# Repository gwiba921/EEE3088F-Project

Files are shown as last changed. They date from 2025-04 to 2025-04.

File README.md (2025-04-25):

# EEE3088F-Project
# EEE3088F Project: Power Subsystem for Micro Mouse Robot

## 📌 Introduction

This project forms part of the EEE3088F course, focusing on the design and development of the **power subsystem** for a maze-solving robot known as a **micro mouse**. The micro mouse achieves autonomous navigation through a system modularized into:

- Processor
- Motherboard
- Sensing
- Power

Our responsibility lies in the **Power Module**, which ensures reliable power delivery to all electronic components of the micro mouse.

---

## ⚙️ 1. Problem Description

The micro mouse requires a stable and efficient power supply to drive its operations, which include movement, sensing, and computation. This project involves designing a power module capable of:

- Powering **four DC motors**
- Integrating **USB-C** for **9V output**
- Regulating **3.3V and 5V power rails**
- Enabling **dual battery charging modes**

All of this must be done while maintaining modular compatibility with the rest of the micro mouse system.

---

## 📐 2. Scope and Limitations

- **Scope**:  
  This project is limited to the **power subsystem only**. However, the design must remain compatible with the processor, motherboard, and sensing modules.

- **Constraints**:
  - Strict budget limit of **$70**
  - **No use of breadboard-based components**
  - Must meet **PCB dimension limits**: `82mm x 60mm`
  - Requires **individual reports** despite collaborative PCB design
  - PCB must be designed from scratch using **permitted components only**

---

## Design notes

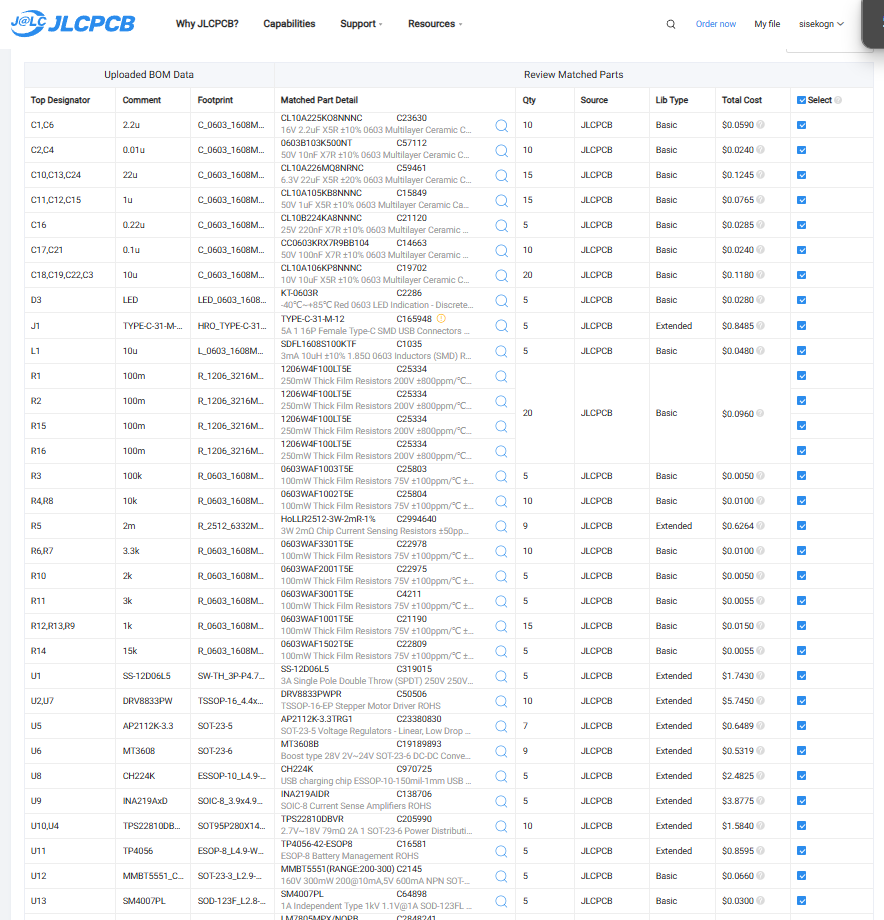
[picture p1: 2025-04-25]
ProLib_pcs_2025-03-23-2025-03-28_040031/jlcpcb/production_files/EEE3088F_Project_JLCPCBBOM_NNKGWI001_PLLCAM006.png

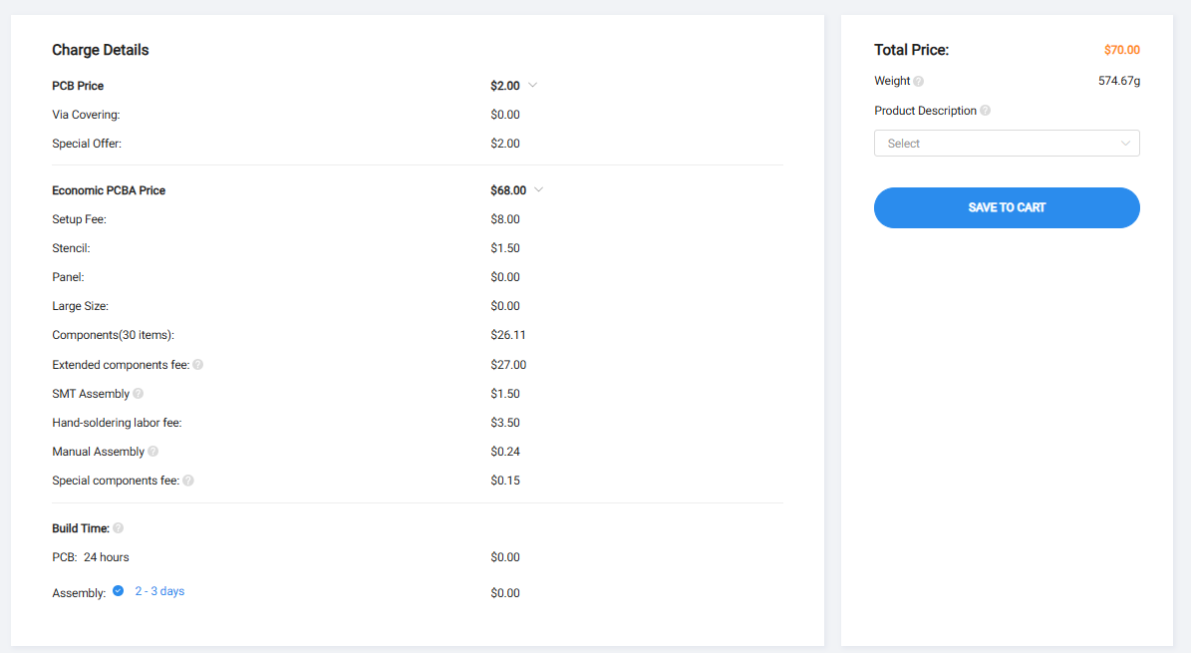
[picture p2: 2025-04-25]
ProLib_pcs_2025-03-23-2025-03-28_040031/jlcpcb/production_files/EEE3088F_Project_JLCPCBacceptance_NNKGWI001_PLLCAM006.png

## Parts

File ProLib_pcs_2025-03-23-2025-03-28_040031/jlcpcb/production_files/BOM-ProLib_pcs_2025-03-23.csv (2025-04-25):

Comment | Designator | Footprint | LCSC | Quantity
10u | L1 | L_0603_1608Metric_Pad1.05x0.95mm_HandSolder | C1035 | 1
INA219AxD | U9 | SOIC-8_3.9x4.9mm_P1.27mm | C138706 | 1
0.1u | C17,C21 | C_0603_1608Metric_Pad1.08x0.95mm_HandSolder | C14663 | 2
1u | C11,C12,C15 | C_0603_1608Metric_Pad1.08x0.95mm_HandSolder | C15849 | 3
TP4056 | U11 | ESOP-8_L4.9-W3.9-P1.27-LS6.0-BL-EP | C16581 | 1
TYPE-C-31-M-12 | J1 | HRO_TYPE-C-31-M-12 | C165948 | 1
MT3608 | U6 | SOT-23-6 | C19189893 | 1
10u | C18,C19,C22,C3 | C_0603_1608Metric_Pad1.08x0.95mm_HandSolder | C19702 | 4
TPS22810DBVR | U10,U4 | SOT95P280X145-6N | C205990 | 2
0.22u | C16 | C_0603_1608Metric_Pad1.08x0.95mm_HandSolder | C21120 | 1
1k | R12,R13,R9 | R_0603_1608Metric_Pad0.98x0.95mm_HandSolder | C21190 | 3
MMBT5551_C2145 | U12 | SOT-23-3_L2.9-W1.3-P1.90-LS2.4-BR | C2145 | 1
15k | R14 | R_0603_1608Metric_Pad0.98x0.95mm_HandSolder | C22809 | 1
LED | D3 | LED_0603_1608Metric_Pad1.05x0.95mm_HandSolder | C2286 | 1
2k | R10 | R_0603_1608Metric_Pad0.98x0.95mm_HandSolder | C22975 | 1
3.3k | R6,R7 | R_0603_1608Metric_Pad0.98x0.95mm_HandSolder | C22978 | 2
AP2112K-3.3 | U5 | SOT-23-5 | C23380830 | 1
2.2u | C1,C6 | C_0603_1608Metric_Pad1.08x0.95mm_HandSolder | C23630 | 2
100k | R3 | R_0603_1608Metric_Pad0.98x0.95mm_HandSolder | C25803 | 1
10k | R4,R8 | R_0603_1608Metric_Pad0.98x0.95mm_HandSolder | C25804 | 2
LM7805MPX_NOPB | VR1 | VREG_LM7805MPX_NOPB | C2848241 | 1
2m | R5 | R_2512_6332Metric_Pad1.40x3.35mm_HandSolder | C2994640 | 1
SS-12D06L5 | U1 | SW-TH_3P-P4.70_L11.1-W12.7 | C319015 | 1
3k | R11 | R_0603_1608Metric_Pad0.98x0.95mm_HandSolder | C4211 | 1
DRV8833PW | U2,U7 | TSSOP-16_4.4x5mm_P0.65mm | C50506 | 2
0.01u | C2,C4 | C_0603_1608Metric_Pad1.08x0.95mm_HandSolder | C57112 | 2
22u | C10,C13,C24 | C_0603_1608Metric_Pad1.08x0.95mm_HandSolder | C59461 | 3
SM4007PL | U13 | SOD-123F_L2.8-W1.8-LS3.7-RD | C64898 | 1
CH224K | U8 | ESSOP-10_L4.9-W3.9-P1.0-LS6.0-TL-EP | C970725 | 1
100m | R2 | R_1206_3216Metric_Pad1.30x1.75mm_HandSolder | C25334 | 1
100m | R1 | R_1206_3216Metric_Pad1.30x1.75mm_HandSolder | C25334 | 1
100m | R15 | R_1206_3216Metric_Pad1.30x1.75mm_HandSolder | C25334 | 1
100m | R16 | R_1206_3216Metric_Pad1.30x1.75mm_HandSolder | C25334 | 1

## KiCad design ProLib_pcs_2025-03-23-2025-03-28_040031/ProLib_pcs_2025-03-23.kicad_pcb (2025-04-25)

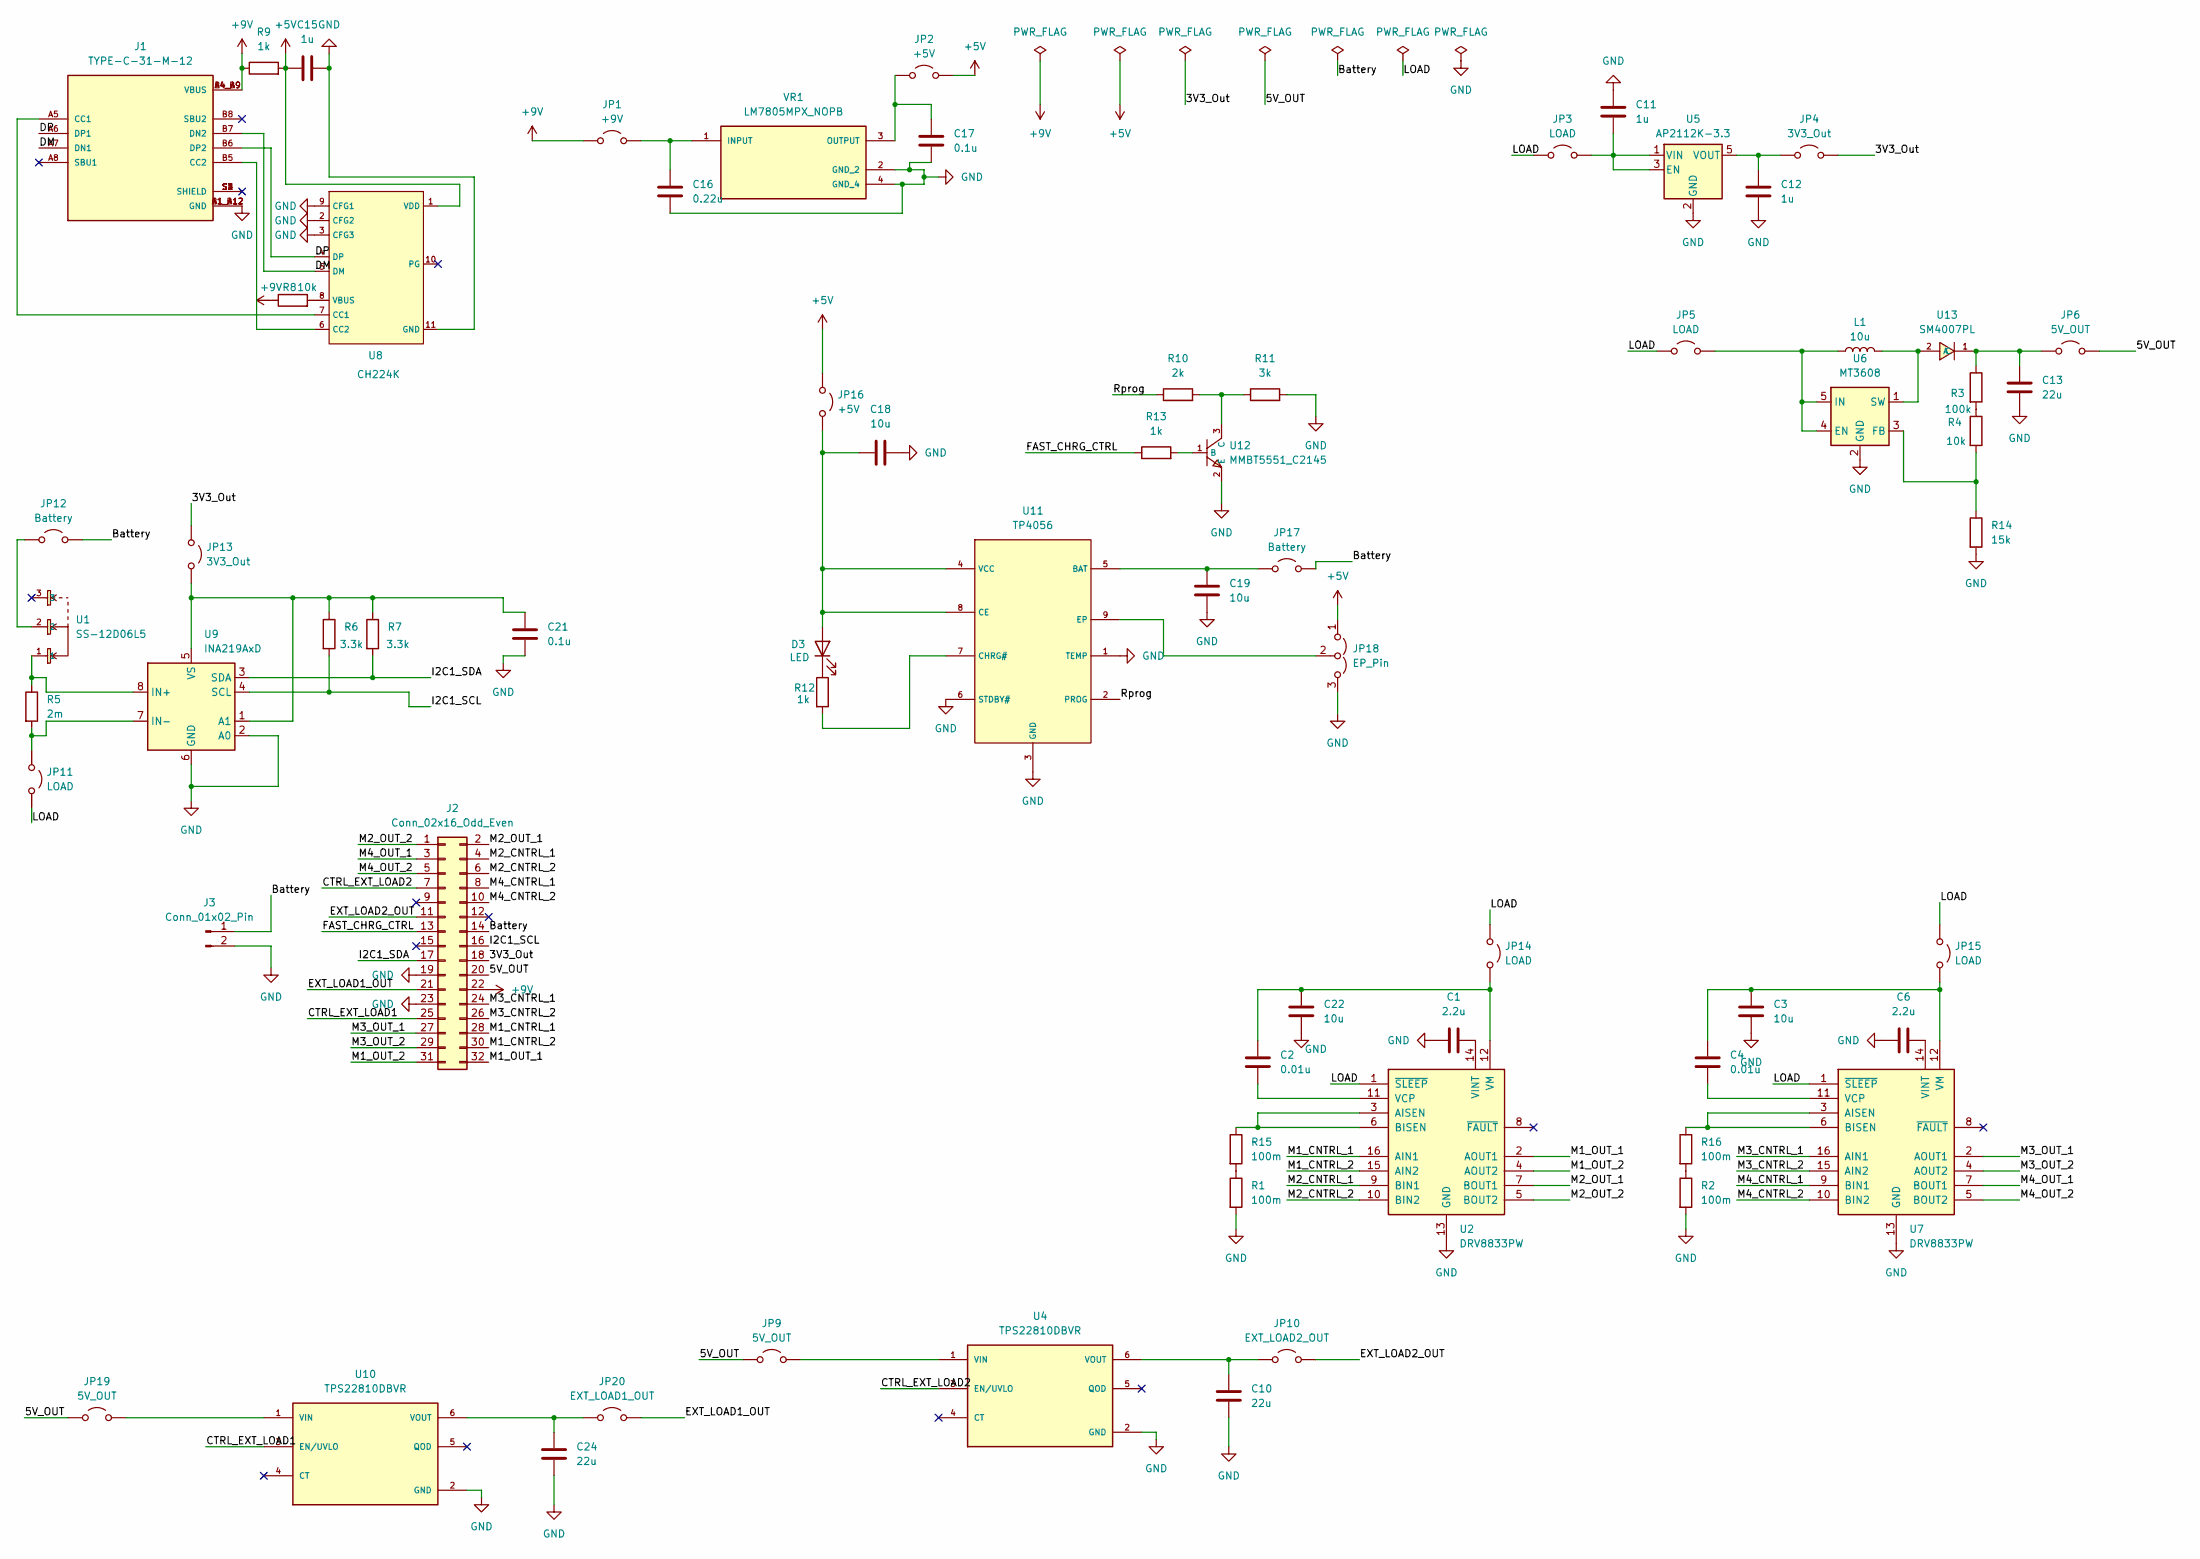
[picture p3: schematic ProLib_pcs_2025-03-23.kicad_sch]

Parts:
C1, C6: 2.2u; C_0603_1608Metric_Pad1.08x0.95mm_HandSolder; LCSC C23630
C2, C4: 0.01u; C_0603_1608Metric_Pad1.08x0.95mm_HandSolder; LCSC C57112
C3, C18, C19, C22: 10u; C_0603_1608Metric_Pad1.08x0.95mm_HandSolder; LCSC C19702
C10, C13, C24: 22u; C_0603_1608Metric_Pad1.08x0.95mm_HandSolder; LCSC C59461
C11, C12, C15: 1u; C_0603_1608Metric_Pad1.08x0.95mm_HandSolder; LCSC C15849
C16: 0.22u; C_0603_1608Metric_Pad1.08x0.95mm_HandSolder; LCSC C21120
C17, C21: 0.1u; C_0603_1608Metric_Pad1.08x0.95mm_HandSolder; LCSC C14663
D3: LED; LED_0603_1608Metric_Pad1.05x0.95mm_HandSolder; LCSC C2286
J1: TYPE-C-31-M-12; HRO_TYPE-C-31-M-12; PARTREV 2020.12.08; LCSC C165948
J2: Conn_02x16_Odd_Even; PinHeader_2x16_P2.54mm_Vertical
J3: Conn_01x02_Pin; JST_PH_S2B-PH-K_1x02_P2.00mm_Horizontal
JP1: +9V; SolderJumper-2_P1.3mm_Open_RoundedPad1.0x1.5mm
JP2, JP16: +5V; SolderJumper-2_P1.3mm_Open_RoundedPad1.0x1.5mm
JP3, JP5, JP11, JP14, JP15: LOAD; SolderJumper-2_P1.3mm_Open_RoundedPad1.0x1.5mm
JP4, JP13: 3V3_Out; SolderJumper-2_P1.3mm_Open_RoundedPad1.0x1.5mm
JP6, JP9, JP19: 5V_OUT; SolderJumper-2_P1.3mm_Open_RoundedPad1.0x1.5mm
JP10: EXT_LOAD2_OUT; SolderJumper-2_P1.3mm_Open_RoundedPad1.0x1.5mm
JP12, JP17: Battery; SolderJumper-2_P1.3mm_Open_RoundedPad1.0x1.5mm
JP18: EP_Pin; SolderJumper-3_P1.3mm_Open_RoundedPad1.0x1.5mm
JP20: EXT_LOAD1_OUT; SolderJumper-2_P1.3mm_Open_RoundedPad1.0x1.5mm
L1: 10u; L_0603_1608Metric_Pad1.05x0.95mm_HandSolder; LCSC C1035
R1, R2, R15, R16: 100m; R_1206_3216Metric_Pad1.30x1.75mm_HandSolder; LCSC C25334
R3: 100k; R_0603_1608Metric_Pad0.98x0.95mm_HandSolder; LCSC C25803
R4, R8: 10k; R_0603_1608Metric_Pad0.98x0.95mm_HandSolder; LCSC C25804
R5: 2m; R_2512_6332Metric_Pad1.40x3.35mm_HandSolder; LCSC C2994640
R6, R7: 3.3k; R_0603_1608Metric_Pad0.98x0.95mm_HandSolder; LCSC C22978
R9, R12, R13: 1k; R_0603_1608Metric_Pad0.98x0.95mm_HandSolder; LCSC C21190
R10: 2k; R_0603_1608Metric_Pad0.98x0.95mm_HandSolder; LCSC C22975
R11: 3k; R_0603_1608Metric_Pad0.98x0.95mm_HandSolder; LCSC C4211
R14: 15k; R_0603_1608Metric_Pad0.98x0.95mm_HandSolder; LCSC C22809
U1: SS-12D06L5; SW-TH_3P-P4.70_L11.1-W12.7; LCSC C319015
U2, U7: DRV8833PW; TSSOP-16_4.4x5mm_P0.65mm; LCSC C50506
U4, U10: TPS22810DBVR; SOT95P280X145-6N; PARTREV C; LCSC C205990
U5: AP2112K-3.3; SOT-23-5; LCSC C23380830
U6: MT3608; SOT-23-6; LCSC C19189893
U8: CH224K; ESSOP-10_L4.9-W3.9-P1.0-LS6.0-TL-EP; LCSC C970725
U9: INA219AxD; SOIC-8_3.9x4.9mm_P1.27mm; LCSC C138706
U11: TP4056; ESOP-8_L4.9-W3.9-P1.27-LS6.0-BL-EP; LCSC C16581
U12: MMBT5551_C2145; SOT-23-3_L2.9-W1.3-P1.90-LS2.4-BR; LCSC C2145
U13: SM4007PL; SOD-123F_L2.8-W1.8-LS3.7-RD; LCSC C64898
VR1: LM7805MPX_NOPB; VREG_LM7805MPX_NOPB; PARTREV L; LCSC C2848241

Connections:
+5V: C15.1, JP2.2 (B), JP16.1 (A), JP18.1 (A), R9.2, U8.1 (VDD)
+9V: J1.A4_B9 (VBUS), J1.B4_A9 (VBUS), J2.22, JP1.1 (A), R8.1, R9.1
/3V3_Out: J2.18, JP4.2 (B), JP13.1 (A)
/5V_OUT: J2.20, JP6.2 (B), JP9.1 (A), JP19.1 (A)
/Battery: J2.14, J3.1, JP12.2 (B), JP17.2 (B)
/CTRL_EXT_LOAD1: J2.25, U10.3 (EN/UVLO)
/CTRL_EXT_LOAD2: J2.7, U4.3 (EN/UVLO)
/DM: J1.A7 (DN1), J1.B7 (DN2), U8.5 (DM)
/DP: J1.A6 (DP1), J1.B6 (DP2), U8.4 (DP)
/EXT_LOAD1_OUT: J2.21, JP20.2 (B)
/EXT_LOAD2_OUT: J2.11, JP10.2 (B)
/FAST_CHRG_CTRL: J2.13, R13.1
/I2C1_SCL: J2.16, R6.2, U9.4 (SCL)
/I2C1_SDA: J2.17, R7.2, U9.3 (SDA)
/LOAD: JP3.1 (A), JP5.1 (A), JP11.2 (B), JP14.1 (A), JP15.1 (A), U2.1 (~SLEEP), U7.1 (~SLEEP)
/M1_CNTRL_1: J2.28, U2.16 (AIN1)
/M1_CNTRL_2: J2.30, U2.15 (AIN2)
/M1_OUT_1: J2.32, U2.2 (AOUT1)
/M1_OUT_2: J2.31, U2.4 (AOUT2)
/M2_CNTRL_1: J2.4, U2.9 (BIN1)
/M2_CNTRL_2: J2.6, U2.10 (BIN2)
/M2_OUT_1: J2.2, U2.7 (BOUT1)
/M2_OUT_2: J2.1, U2.5 (BOUT2)
/M3_CNTRL_1: J2.24, U7.16 (AIN1)
/M3_CNTRL_2: J2.26, U7.15 (AIN2)
/M3_OUT_1: J2.27, U7.2 (AOUT1)
/M3_OUT_2: J2.29, U7.4 (AOUT2)
/M4_CNTRL_1: J2.8, U7.9 (BIN1)
/M4_CNTRL_2: J2.10, U7.10 (BIN2)
/M4_OUT_1: J2.3, U7.7 (BOUT1)
/M4_OUT_2: J2.5, U7.5 (BOUT2)
/Rprog: R10.1, U11.2 (PROG)
GND: C1.1, C3.2, C6.1, C10.2, C11.1, C12.2, C13.2, C15.2, C16.2, C17.2, C18.2, C19.2, C21.2, C22.2, C24.2, J1.A1_B12 (GND), J1.B1_A12 (GND), J2.19, J2.23, J3.2, JP18.3 (B), R1.2, R2.2, R11.2, R14.2, U2.13 (GND), U4.2 (GND), U5.2 (GND), U6.2 (GND), U7.13 (GND), U8.2 (CFG2), U8.3 (CFG3), U8.9 (CFG1), U8.11 (GND), U9.2 (A0), U9.6 (GND), U10.2 (GND), U11.1 (TEMP), U11.3 (GND), U11.6 (STDBY#), U12.2 (E), VR1.2 (GND_2), VR1.4 (GND_4)
unnamed: C18.1, D3.2 (A), JP16.2 (B), U11.4 (VCC), U11.8 (CE)
unnamed: D3.1 (K), R12.1
unnamed: J1.A5 (CC1), U8.7 (CC1)
unnamed: J1.B5 (CC2), U8.6 (CC2)
unnamed: C16.1, JP1.2 (B), VR1.1 (INPUT)
unnamed: C17.1, JP2.1 (A), VR1.3 (OUTPUT)
unnamed: C11.2, JP3.2 (B), U5.1 (VIN), U5.3 (EN)
unnamed: C12.1, JP4.1 (A), U5.5 (VOUT)
unnamed: JP5.2 (B), L1.1, U6.4 (EN), U6.5 (IN)
unnamed: C13.1, JP6.1 (A), R3.1, U13.1 (C)
unnamed: JP9.2 (B), U4.1 (VIN)
unnamed: C10.1, JP10.1 (A), U4.6 (VOUT)
unnamed: JP11.1 (A), R5.2, U9.7 (IN-)
unnamed: JP12.1 (A), U1.2
unnamed: C21.1, JP13.2 (B), R6.1, R7.1, U9.1 (A1), U9.5 (VS)
unnamed: C2.1, C22.1, JP14.2 (B), U2.12 (VM)
unnamed: C3.1, C4.1, JP15.2 (B), U7.12 (VM)
unnamed: C19.1, JP17.1 (A), U11.5 (BAT)
unnamed: JP18.2 (C), U11.9 (EP)
unnamed: JP19.2 (B), U10.1 (VIN)
unnamed: C24.1, JP20.1 (A), U10.6 (VOUT)
unnamed: R1.1, R15.2
unnamed: R3.2, R4.1
unnamed: R2.1, R16.2
unnamed: R15.1, U2.3 (AISEN), U2.6 (BISEN)
unnamed: C2.2, U2.11 (VCP)
unnamed: C1.2, U2.14 (VINT)
unnamed: R4.2, R14.1, U6.3 (FB)
unnamed: R16.1, U7.3 (AISEN), U7.6 (BISEN)
unnamed: C4.2, U7.11 (VCP)
unnamed: C6.2, U7.14 (VINT)
unnamed: R8.2, U8.8 (VBUS)
unnamed: R5.1, U1.1, U9.8 (IN+)
unnamed: R12.2, U11.7 (CHRG#)
unnamed: R13.2, U12.1 (B)
unnamed: R10.2, R11.1, U12.3 (C)
unnamed: L1.2, U6.1 (SW), U13.2 (A)

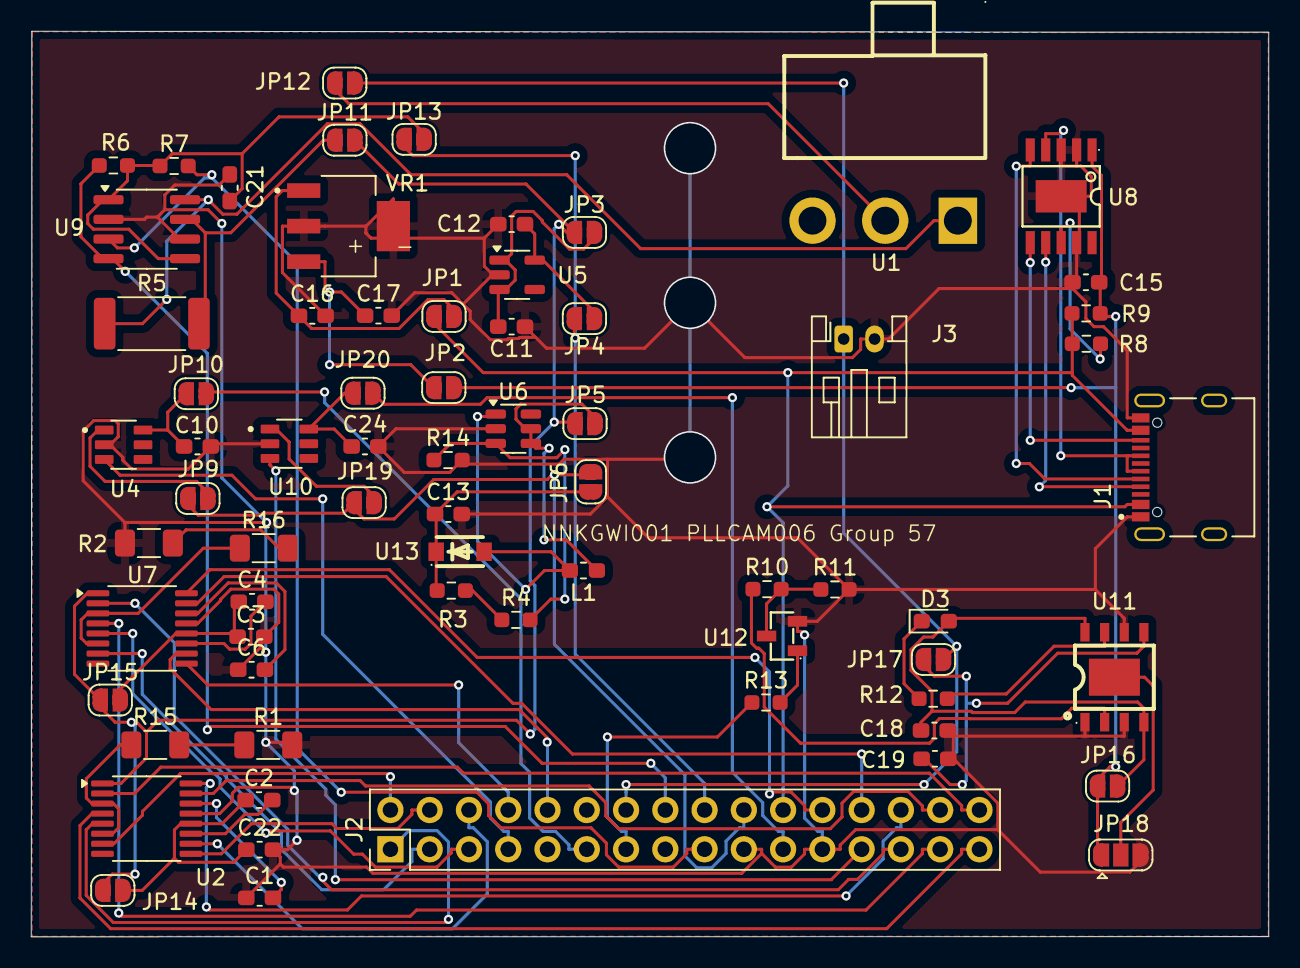
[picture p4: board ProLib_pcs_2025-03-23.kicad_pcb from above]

Board: 2 copper layers, 80.0 x 58.6 mm, 69 parts (0 on the bottom side), 70 nets.
